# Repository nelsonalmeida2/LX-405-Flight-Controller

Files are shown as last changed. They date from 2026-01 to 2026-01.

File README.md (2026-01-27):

<div align="center">

# 🚁 LX-405 Flight Controller

<div align="center">
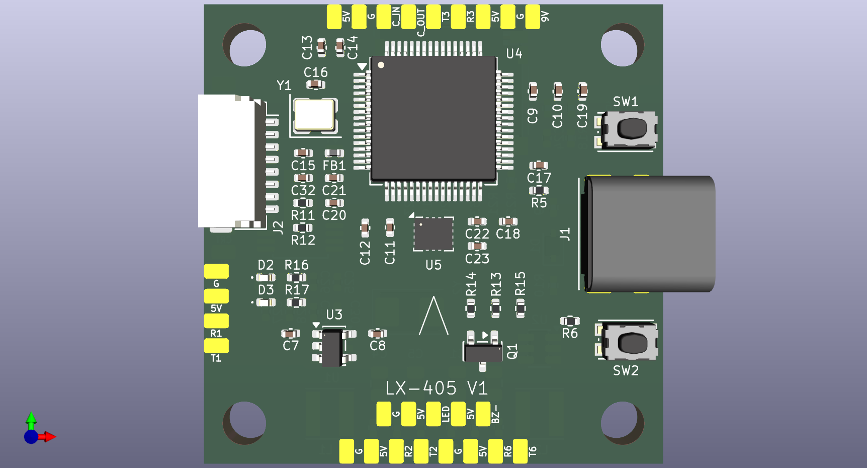
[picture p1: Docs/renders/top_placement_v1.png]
LX-405 PCB Placement
  
</div>

**A robust, Open Source FPV Flight Controller designed by a Computer Engineering student.**






</div>

---

## 🎯 Motivation & Philosophy

> *"In the modern era, Artificial Intelligence combined with human effort makes the impossible, inevitable."*

The **LX-405** project was born from a realization: as a Computer Engineering student entering the high-speed world of FPV, I found that too many flight controllers on the market suffer from electrical noise, weak regulators, and fragility under 6S voltage spikes.

My goal is to prove that **modern engineering is boundary-less**. Even though my degree is not strictly focused on electronics, the foundational skills acquired in my academic path—combined with a self-taught mindset and the leverage of **Large Language Models (LLMs)** as advanced design assistants—allow for the creation of professional-grade hardware.

This project demonstrates that with the right theoretical foundations and modern AI tools, it is possible to design a Flight Controller that is **more robust, cleaner, and potentially more cost-effective** at scale.

### 📐 Design Strategy: Modular & Hierarchical
Unlike typical hobbyist "flat" schematics, the LX-405 follows a strict **Hierarchical Design** approach.
Applying the software engineering principle of **Modularity** (Separation of Concerns), the hardware is divided into distinct hierarchical subsystems:
* **Power Management:** Encapsulates the voltage regulation logic (5V, 9V, 3.3V) with clean "Power Flags" logic.
* **MCU Core:** Contains the processor logic, clock, signaling, and boot configuration.
* **System Peripherals:** Groups active sensors (Gyro, Baro), OSD video processing logic, **Blackbox Logging**, and user feedback systems (LEDs/Buzzer).
* **Connectors IO:** Isolates physical interface definitions (plugs/pads) from logical connections to prevent routing conflicts.

### 🎓 Academic Foundations
This design applies core concepts from my Computer Engineering curriculum at **Universidade Lusófona**:
* **Digital Systems:** Logic gates and boolean algebra applied to circuit switching.
* **Computer Architecture:** Understanding CPU data paths, buses, registers, and instruction execution.
* **Advanced Computer Architectures:** Knowledge of processor constraints, memory hierarchy (cache), and hardware-software interaction.
* **Fundamentals of Physics:** Electromagnetism, electric fields, circuit analysis, and DC power dynamics.

---

## ⚡ Technical Specifications

### 🧠 Core System (Schematic Completed)
* **MCU:** STM32F405RGT6 (168MHz, 1MB Flash).
* **Clock:** 8MHz HSE Crystal Oscillator with 22pF load caps for precision timing.
* **Signal Integrity:** Dedicated LC Filter (Ferrite Bead + Caps) for **VDDA** analog noise suppression.
* **Safety:** Hardware-implemented Watchdog (NRST) and Bootloader (BOOT0) physical controls.

### 📡 Connectivity & Protocols
* **USB Interface:** Modern **USB-C** connector with dedicated ESD protection lines for firmware updates and Betaflight configuration.
* **Motor Protocols:**
    * 4x DSHOT Outputs (Timer-mapped for DMA collision avoidance).
    * **Redundant ESC Pads:** Parallel solder pads for motor signals, allowing field repairs if the main JST connector breaks.
* **Communication Ports:** 5x UARTs fully mapped for versatility:
    * **UART 1:** RC Link (ELRS / Crossfire).
    * **UART 2:** GPS / General Purpose.
    * **UART 3:** **Video Link** (SmartAudio for Analog **OR** MSP for DJI O3/HDZero).
    * **UART 4:** ESC Telemetry (Sensor Input).
    * **UART 6:** Peripheral Expansion (Bluetooth, Lidar, Secondary GPS).
    * *(Note: UART 5 was replaced by the High-Speed SDIO Bus).*
* **Video System (Hybrid):**
    * Dedicated **"Hybrid Power Pad"** offering both **5V** (Analog) and **9V** (High Power Digital) options for the VTX.
    * **Analog OSD:** **MAX7456** (or **AT7456E**) on SPI2 with dedicated video filtering.
* **Sensor Bus:** Dedicated SPI1 (High-Speed Gyro) and I2C1 (Barometer).

### 🛡️ On-Board Sensors & Peripherals
* **IMU (Gyroscope):** **BMI270** connected via Low-Noise **SPI1**.
    * Features hardware **EXTI Interrupt** (PC4) for ultra-low latency loop synchronization.
* **Barometer:** **DPS310** connected via **I2C1** for high-precision altitude hold.
* **Blackbox Logging:** **MicroSD Card Slot** via **4-bit SDIO** Interface.
    * Superior performance compared to SPI logging, enabling high-frequency data recording without CPU bottlenecks.
* **User Feedback:**
    * **Status LEDs:** Dedicated **LED_POWER** (Red) and **LED_STATUS** (Blue) for instant system diagnostics.
    * **Buzzer Driver:** Integrated active buzzer circuit for alarms and "turtle mode" feedback.

### 🔋 Power Plant (Tri-Rail Architecture)
A hierarchical power distribution system designed to minimize noise coupling and maximize versatility:

| Rail | Regulator | Specs | Application |
| :--- | :--- | :--- | :--- |
| **Input** | XT60 Direct | **3S-6S (10V - 25.2V)** | Wide-range input for Cinematic (6S) & Freestyle (4S) |
| **9V Rail** | TPS54302 | 3A Buck | **Hybrid Video Ready:** Supports DJI O3/Vista & Analog VTX |
| **5V Rail** | TPS54302 | 3A Buck | GPS, ELRS Receiver, Buzzer, OSD Chip |
| **3.3V Rail** | AP2112K | 500mA LDO | **Ultra-Low Noise** for MCU, Gyro, Baro & Blackbox |

---

## 📂 Repository Structure

```text
LX-405-Flight-Controller/
├── 📂 Hardware/          # KiCad Project Files (Schematics, PCB & Symbols)
├── 📂 Schematic/         # PDF Exports for easy viewing
├── 📂 Docs/              # Datasheets and Engineering Notes
├── 📄 LICENSE            # MIT License details
└── 📄 README.md          # Documentation
```
## 🛠 Development Roadmap

### Phase 1: Schematic Design 🔌

- [x] **Power Management**
    - [x] Input Stage: TVS protection and bulk capacitance (3S–6S filtering)
    - [x] 5V Regulator: Synchronous buck (TPS54302)
    - [x] 9V Regulator: High-current buck (TPS54302) for HD video
    - [x] 3.3V Regulator: Low-noise LDO (AP2112K) for sensors

- [x] **MCU Core**
    - [x] STM32F405RGT6: Symbol integration and pin definition
    - [x] Power decoupling & analog filtering (VDDA)
    - [x] Clock system: 8 MHz HSE crystal
    - [x] I/O architecture: Full UART / SPI / I2C mapping validation

- [x] **System Peripherals**
    - [x] Gyroscope (BMI270) via SPI1
    - [x] Barometer (DPS310) via I2C with address fix
    - [x] Blackbox: High-speed SDIO MicroSD slot implementation
    - [x] On-screen display (MAX7456 / AT7456E) via SPI2
    - [x] Visual / Audio: Status LEDs & buzzer circuit implemented

- [x] **Connectors & I/O**
    - [x] USB-C interface (data lines & ESD protection logic)
    - [x] ESC connector (standard pinout with telemetry)
    - [x] ESC redundancy: Parallel solder pads for emergency field repairs
    - [x] Hybrid VTX connector (selectable 5V / 9V)

- [x] **Design Validation**
    - [x] Electrical Rules Check (ERC): **PASSED with 0 errors**
    - [x] Schematic design finalized (**v0.6**)

### Phase 2: PCB Layout 📐

- [x] **Physical Implementation**
    - [x] Assign footprints (associating symbols with physical dimensions)
    - [x] Stackup definition (4-layer)
    - [x] Component placement (Optimized for noise reduction & assembly)
    - [x] Silkscreen & Labeling (User-friendly pin identification)
    - [ ] Routing (Traces & Ground Planes)
    - [ ] DRC (Design Rules Check) & Fabrication Output (Gerbers)

---

## 📜 License

This project is licensed under the **MIT License** — see the `LICENSE` file for details.

You are free to use, modify, and distribute this hardware design for private or commercial use, provided you include the original copyright notice.

As an **Open Source Hardware** project, contributions and forks are welcome.

---

<div align="center">

**Designed in Lisbon, Portugal 🇵🇹**  
Powered by Engineering Fundamentals & AI

</div>

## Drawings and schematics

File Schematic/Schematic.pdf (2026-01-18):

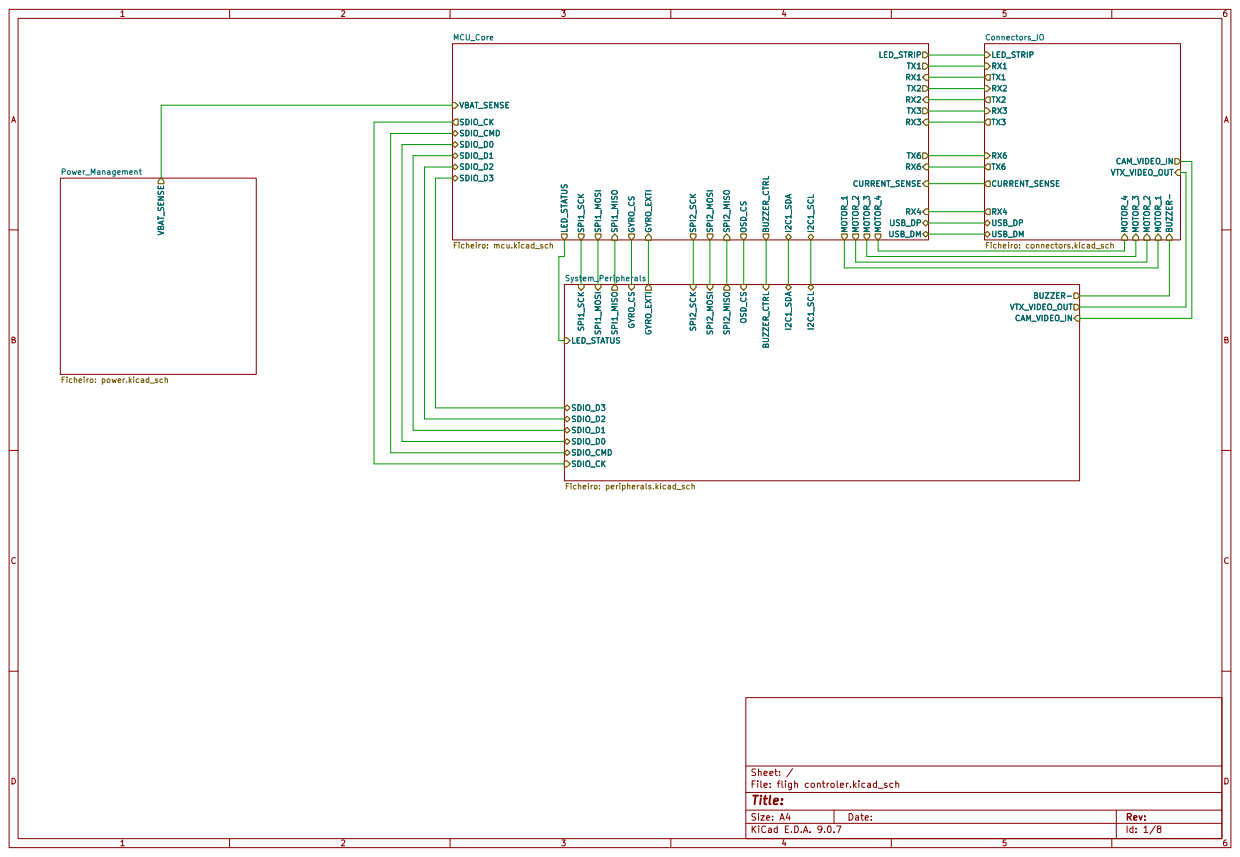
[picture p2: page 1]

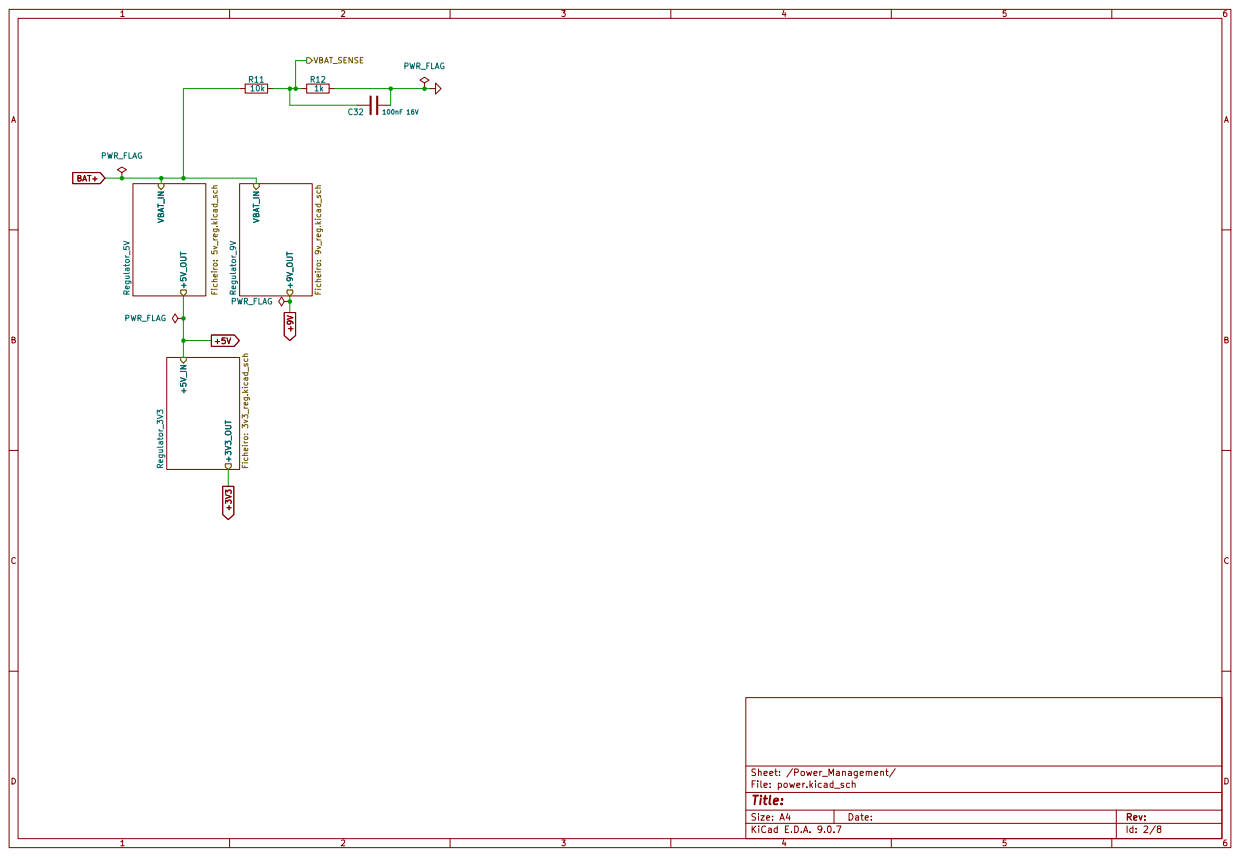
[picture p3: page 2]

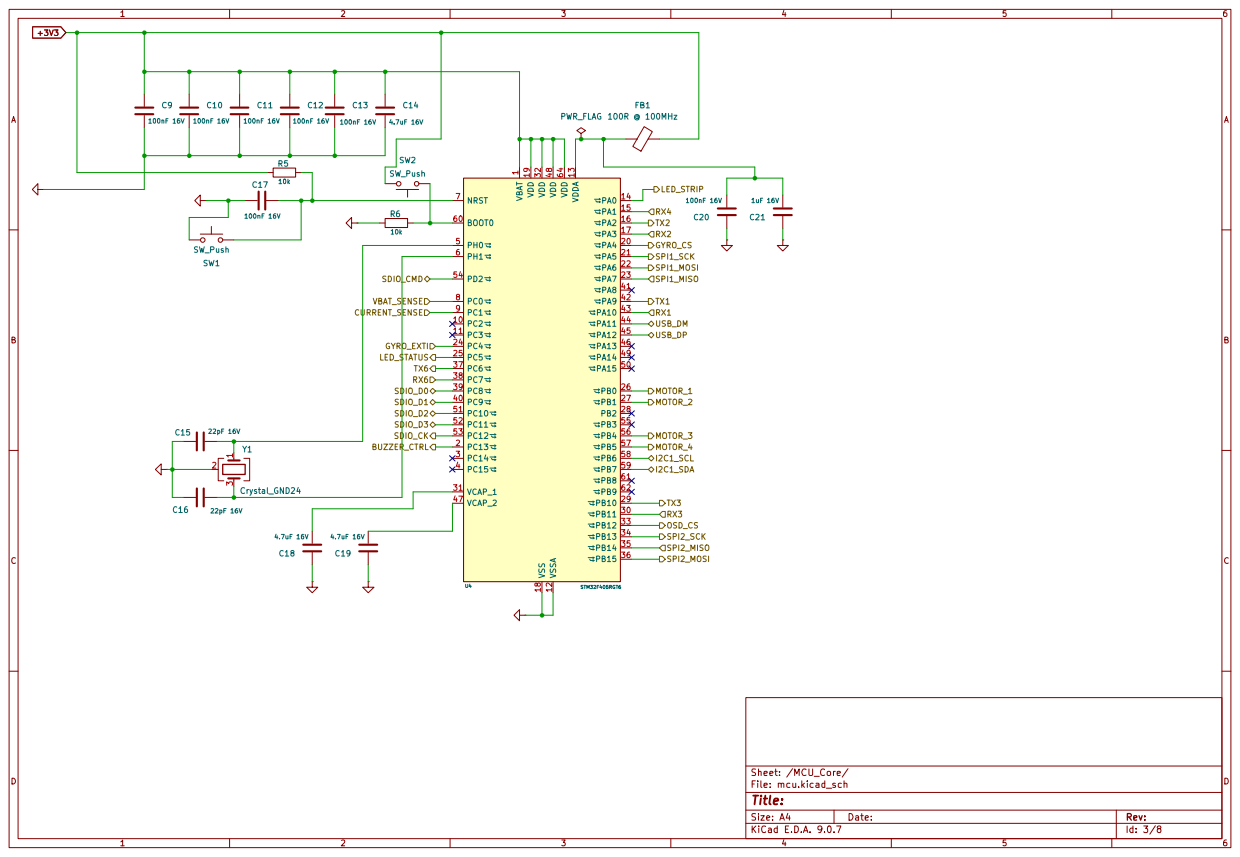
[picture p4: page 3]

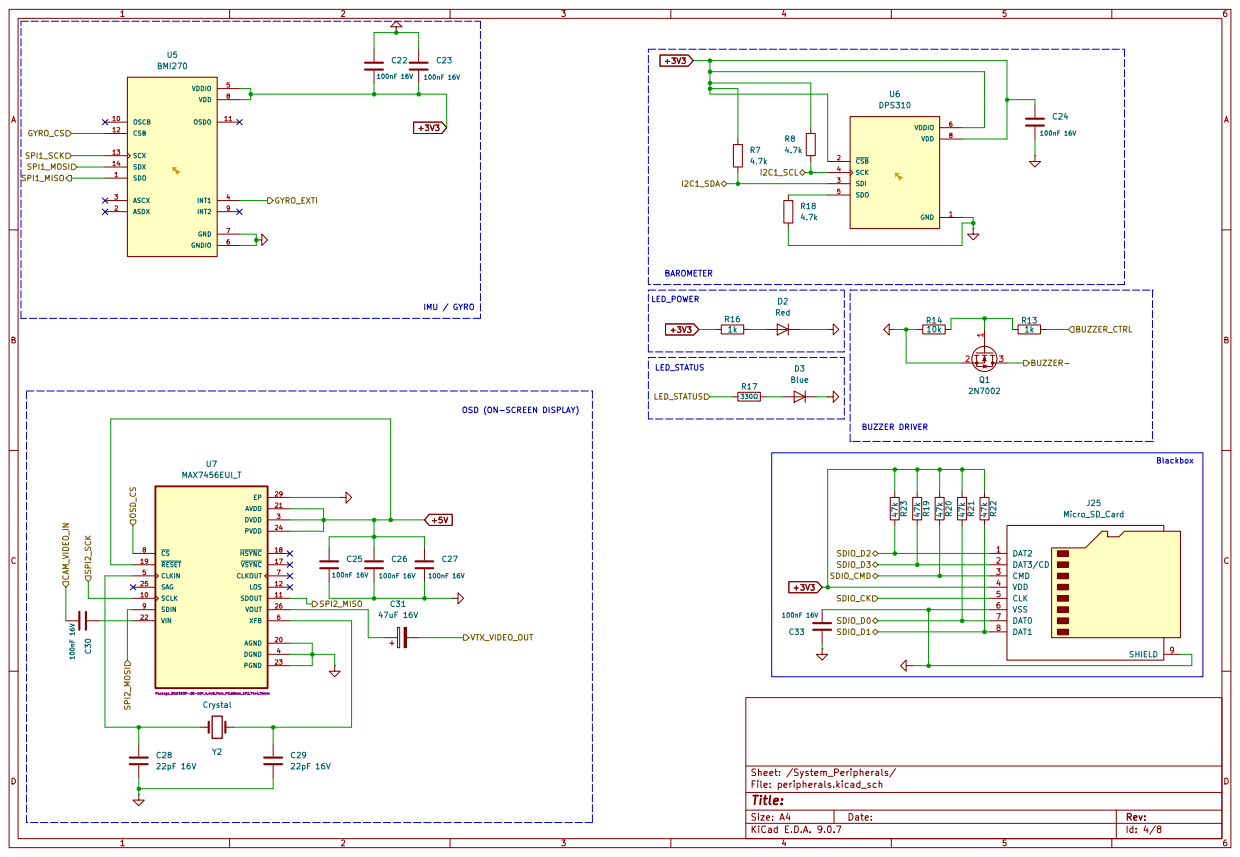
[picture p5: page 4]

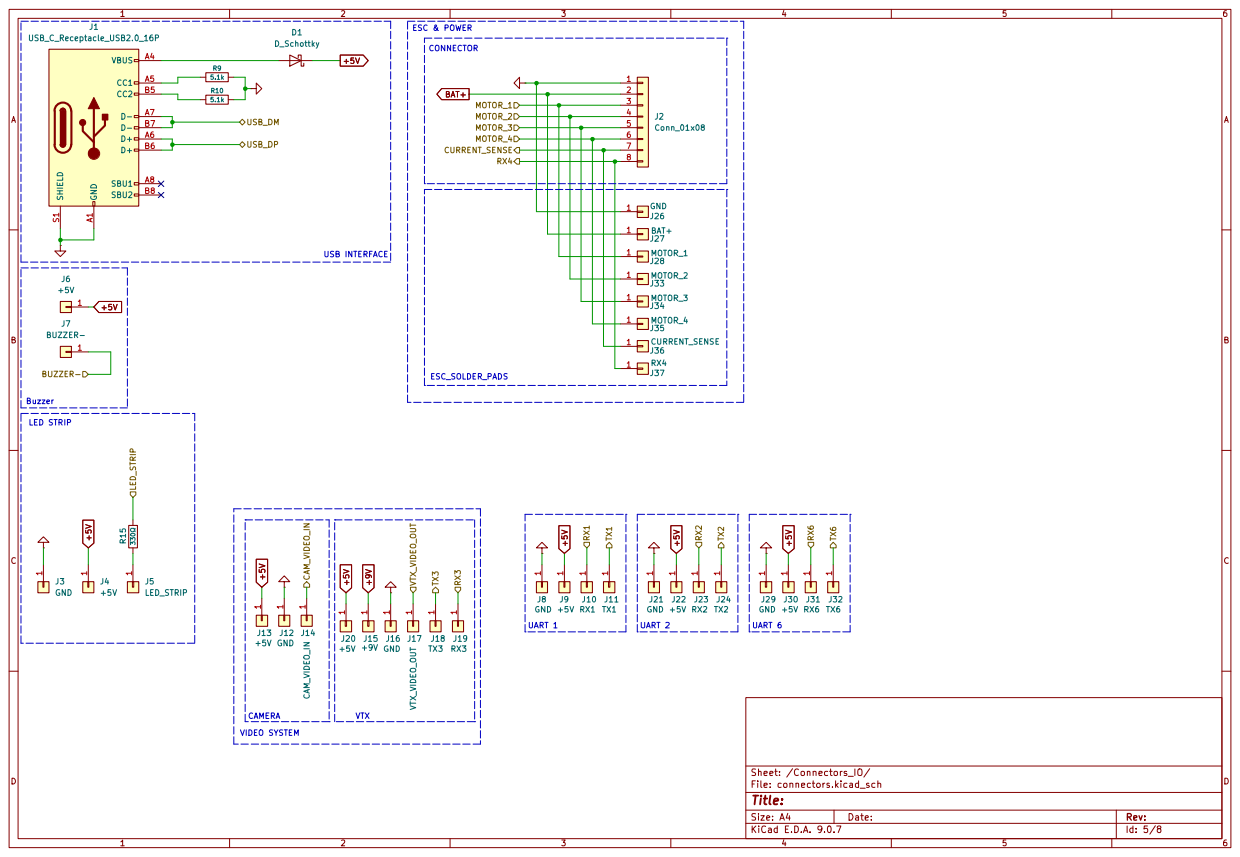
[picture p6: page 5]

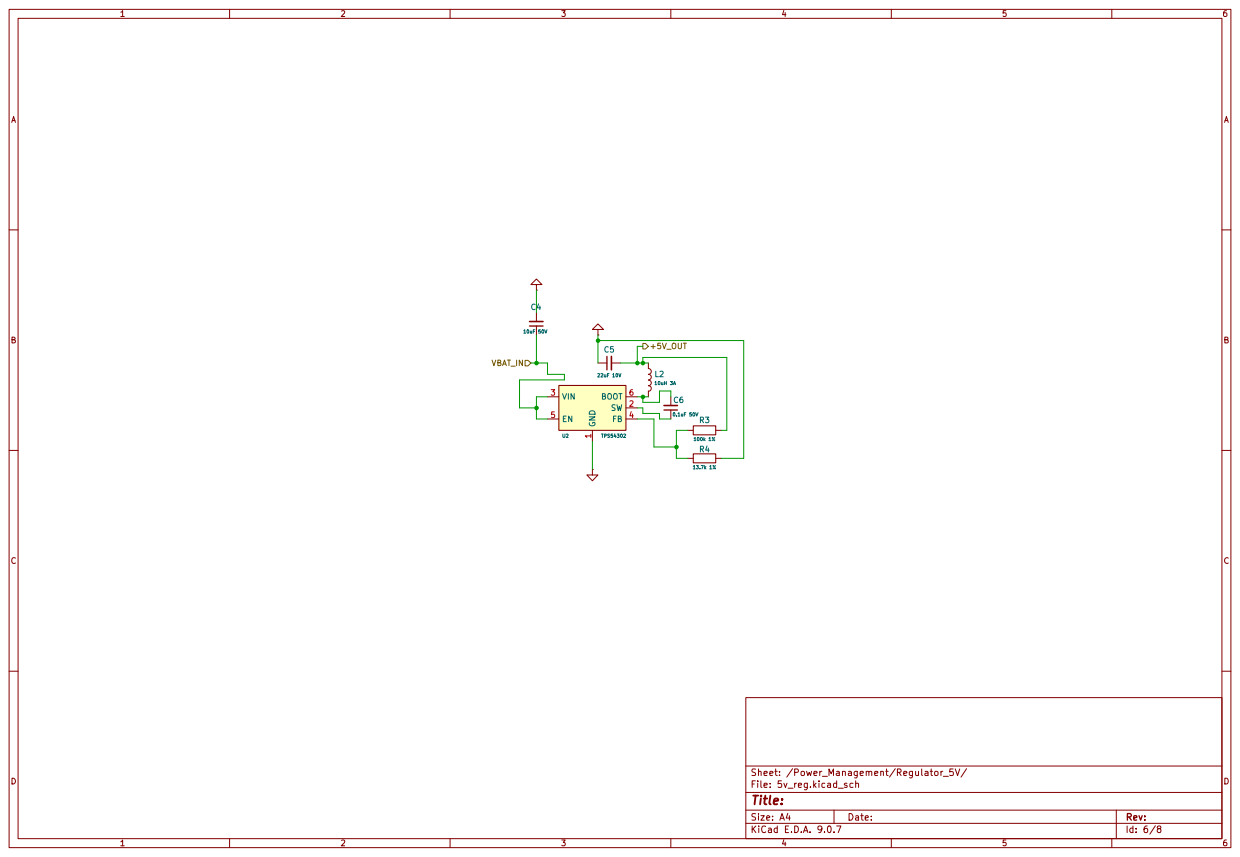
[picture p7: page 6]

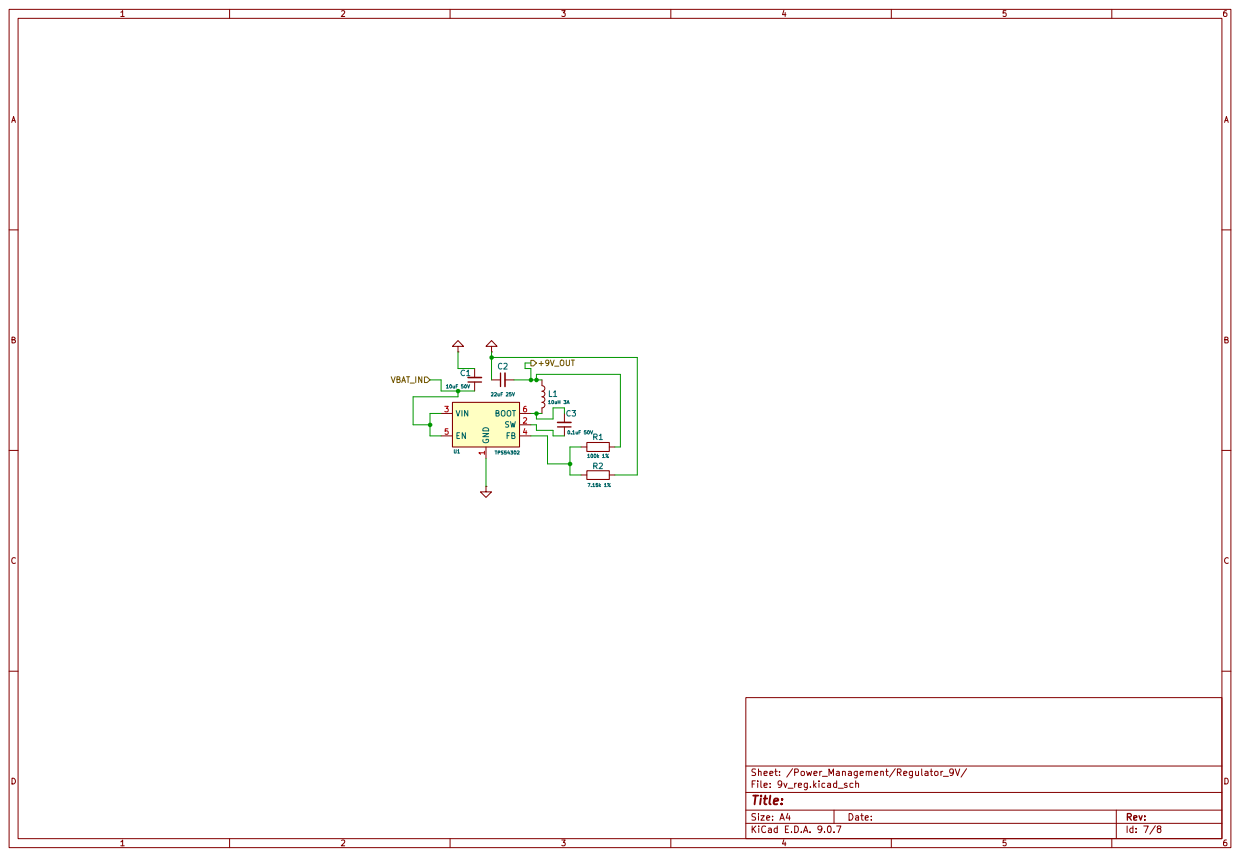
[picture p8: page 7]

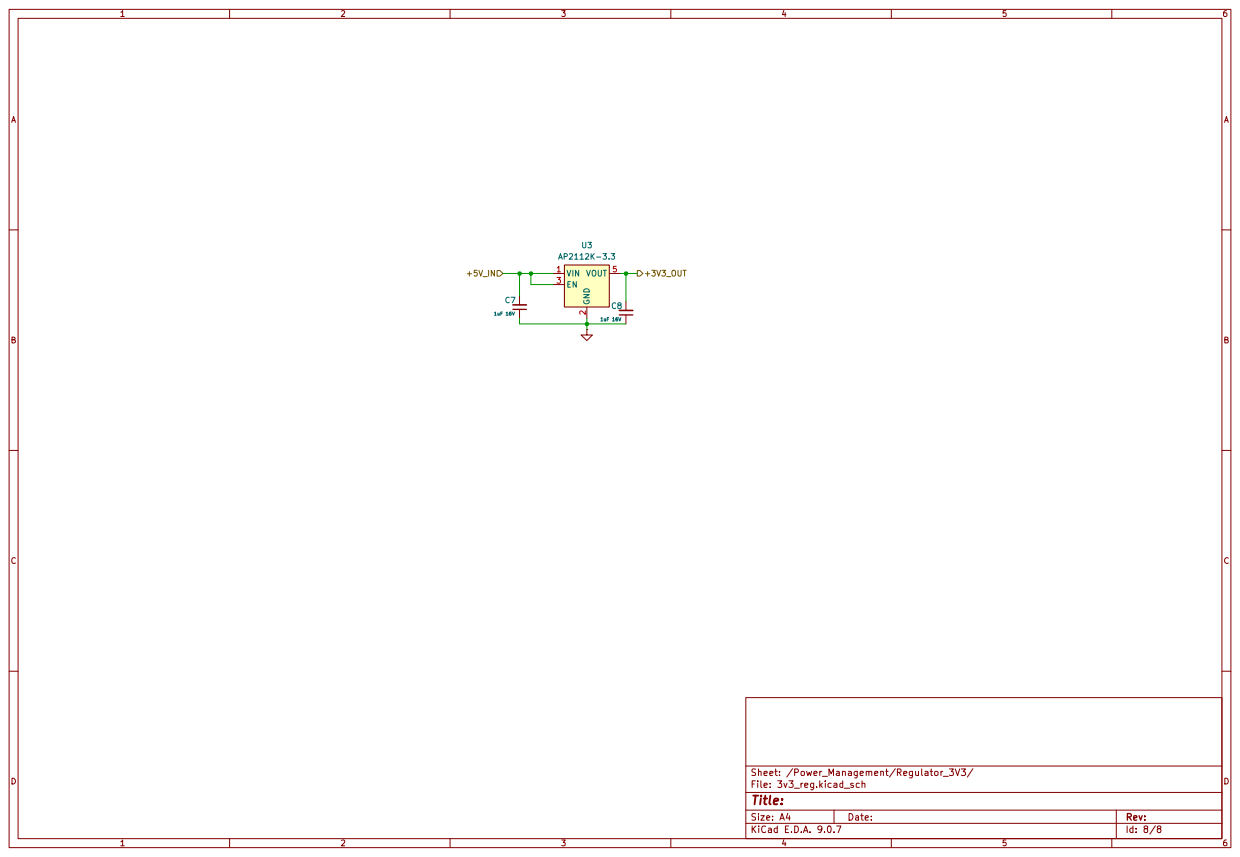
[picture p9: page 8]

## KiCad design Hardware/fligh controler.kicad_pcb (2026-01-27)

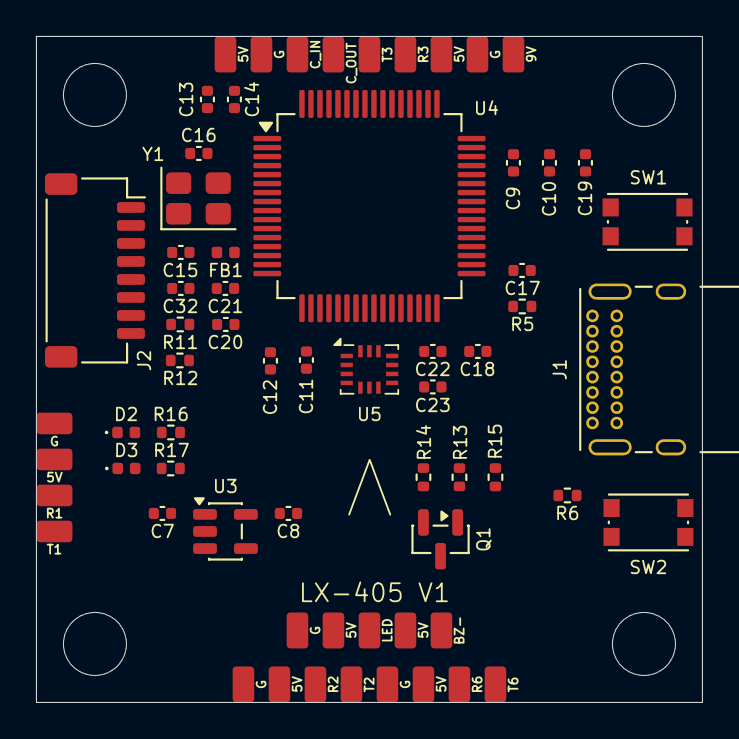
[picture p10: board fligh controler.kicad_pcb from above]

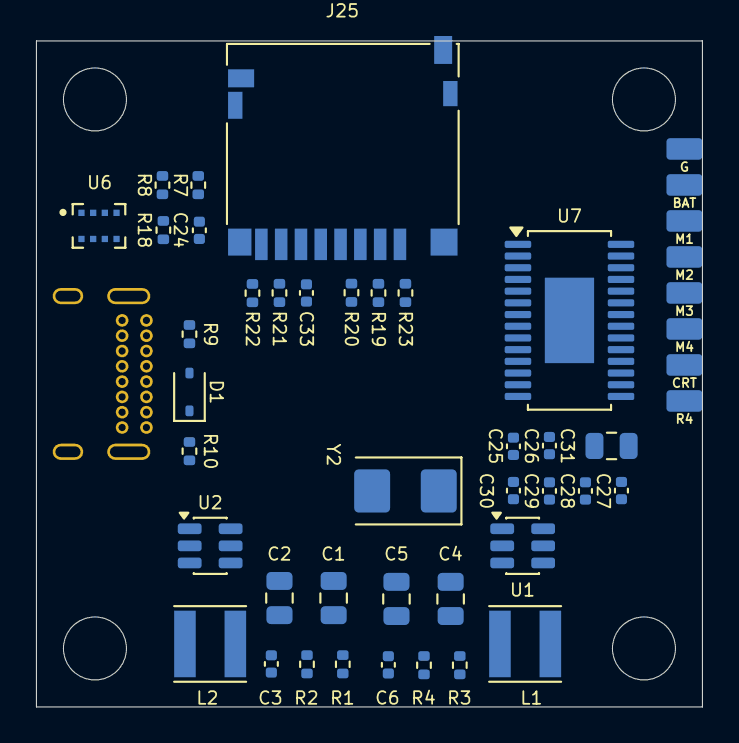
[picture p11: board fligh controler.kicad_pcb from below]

Board: 2 copper layers, 37.0 x 37.0 mm, 111 parts (46 on the bottom side), 70 nets, no tracks yet.

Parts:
5V, 5V#2, 5V#3, 5V#4, 5V#5, 5V#6, 5V#7: +5V; Pad_TestPoint_Retangular
9V: +9V; Pad_TestPoint_Retangular
BAT: BAT+; Pad_TestPoint_Retangular
BZ-: BUZZER-; Pad_TestPoint_Retangular
C1, C4: 10uF 50V; C_0805_2012Metric
C2: 22uF 25V; C_0805_2012Metric
C3, C6: 0.1uF 50V; C_0402_1005Metric
C5: 22uF 10V; C_0805_2012Metric
C7, C8, C21: 1uF 16V; C_0402_1005Metric
C9, C10, C11, C12, C13, C17, C20, C22, C23, C24, C25, C26, C27, C30, C32, C33: 100nF 16V; C_0402_1005Metric
C14, C18, C19: 4.7uF 16V; C_0402_1005Metric
C15, C16, C28, C29: 22pF 16V; C_0402_1005Metric
C31: 47uF 16V; C_0805_2012Metric
CRT: CURRENT_SENSE; Pad_TestPoint_Retangular
C_IN: CAM_VIDEO_IN; Pad_TestPoint_Retangular
C_OUT: VTX_VIDEO_OUT; Pad_TestPoint_Retangular
D1: D_Schottky; D_SOD-323
D2: Red; LED_0402_1005Metric
D3: Blue; LED_0402_1005Metric
FB1: 100R @ 100MHz; L_0402_1005Metric
G: GND; Pad_TestPoint_Retangular
G#2, G#3, G#4, G#5, G#6, G#7: GND; Pad_TestPoint_Retangular
J1: USB_C_Receptacle_USB2.0_16P; USB_C_Receptacle_GCT_USB4085
J2: Conn_01x08; JST_SH_SM08B-SRSS-TB_1x08-1MP_P1.00mm_Horizontal
J25: Micro_SD_Card; microSD_HC_Hirose_DM3D-SF
L1, L2: 10uH 3A; L_Taiyo-Yuden_NR-40xx
LED: LED_STRIP; Pad_TestPoint_Retangular
M1: MOTOR_1; Pad_TestPoint_Retangular
M2: MOTOR_2; Pad_TestPoint_Retangular
M3: MOTOR_3; Pad_TestPoint_Retangular
M4: MOTOR_4; Pad_TestPoint_Retangular
Q1: 2N7002; SOT-23
R1: RX1; Pad_TestPoint_Retangular
R1#2, R3#2: 100k 1%; R_0402_1005Metric
R2: RX2; Pad_TestPoint_Retangular
R2#2: 7.15k 1%; R_0402_1005Metric
R3: RX3; Pad_TestPoint_Retangular
R4: RX4; Pad_TestPoint_Retangular
R4#2: 13.7k 1%; R_0402_1005Metric
R5, R6, R11, R14: 10k; R_0402_1005Metric
R6#2: RX6; Pad_TestPoint_Retangular
R7, R8, R18: 4.7k; R_0402_1005Metric
R9, R10: 5.1k; R_0402_1005Metric
R12, R13, R16: 1k; R_0402_1005Metric
R15, R17: 330Ω; R_0402_1005Metric
R19, R20, R21, R22, R23: 47k; R_0402_1005Metric
SW1, SW2: SW_Push; SW_Push_1P1T_NO_CK_KMR2
T1: TX1; Pad_TestPoint_Retangular
T2: TX2; Pad_TestPoint_Retangular
T3: TX3; Pad_TestPoint_Retangular
T6: TX6; Pad_TestPoint_Retangular
U1, U2: TPS54302; SOT-23-6
U3: AP2112K-3.3; SOT-23-5
U4: STM32F405RGT6; LQFP-64_10x10mm_P0.5mm
U5: BMI270; Bosch_LGA-14_3x2.5mm_P0.5mm
U6: DPS310
U7: MAX7456EUI_T; TSSOP-28-1EP_4.4x9.7mm_P0.65mm_EP2.74x4.75mm
Y1: Crystal_GND24; Crystal_SMD_3225-4Pin_3.2x2.5mm
Y2: Crystal; Crystal_SMD_5032-2Pin_5.0x3.2mm

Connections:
+3V3: C8.2, C9.1, C10.1, C11.1, C12.1, C13.1, C14.1, C22.2, C23.2, C24.1, FB1.2, J25.4 (VDD), R5.1, R7.1, R8.2, R16.1, R19.1, R20.1, R21.1, R22.1, R23.1, SW2.2, U3.5 (VOUT), U4.1 (VBAT), U4.19 (VDD), U4.32 (VDD), U4.48 (VDD), U4.64 (VDD), U5.5 (VDDIO), U5.8 (VDD), U6.2 (~CSB), U6.6 (VDDIO), U6.8 (VDD)
+5V: 5V.1, 5V#2.1, 5V#3.1, 5V#4.1, 5V#5.1, 5V#6.1, 5V#7.1, C5.2, C7.2, C25.1, C26.1, C27.1, D1.1 (K), L2.1, R3#2.2, U3.1 (VIN), U3.3 (EN), U7.3 (DVDD), U7.19 (~RESET), U7.21 (AVDD), U7.24 (PVDD)
+9V: 9V.1, C2.2, L1.1, R1#2.2
/Connectors_IO/BUZZER-: BZ-.1, Q1.3 (D)
/Connectors_IO/CAM_VIDEO_IN: C30.2, C_IN.1
/Connectors_IO/CURRENT_SENSE: CRT.1, J2.7, U4.9 (PC1)
/Connectors_IO/LED_STRIP: R15.1, U4.14 (PA0)
/Connectors_IO/MOTOR_1: J2.3, M1.1, U4.26 (PB0)
/Connectors_IO/MOTOR_2: J2.4, M2.1, U4.27 (PB1)
/Connectors_IO/MOTOR_3: J2.5, M3.1, U4.56 (PB4)
/Connectors_IO/MOTOR_4: J2.6, M4.1, U4.57 (PB5)
/Connectors_IO/RX1: R1.1, U4.42 (PA9)
/Connectors_IO/RX2: R2.1, U4.16 (PA2)
/Connectors_IO/RX3: R3.1, U4.29 (PB10)
/Connectors_IO/RX4: J2.8, R4.1, U4.15 (PA1)
/Connectors_IO/RX6: R6#2.1, U4.37 (PC6)
/Connectors_IO/TX1: T1.1, U4.43 (PA10)
/Connectors_IO/TX2: T2.1, U4.17 (PA3)
/Connectors_IO/TX3: T3.1, U4.30 (PB11)
/Connectors_IO/TX6: T6.1, U4.38 (PC7)
/Connectors_IO/USB_DM: J1.A7 (D-), J1.B7 (D-), U4.44 (PA11)
/Connectors_IO/USB_DP: J1.A6 (D+), J1.B6 (D+), U4.45 (PA12)
/Connectors_IO/VTX_VIDEO_OUT: C31.2, C_OUT.1
/MCU_Core/BUZZER_CTRL: R13.2, U4.2 (PC13)
/MCU_Core/GYRO_CS: U4.20 (PA4), U5.12 (CSB)
/MCU_Core/GYRO_EXTI: U4.24 (PC4), U5.4 (INT1)
/MCU_Core/I2C1_SCL: R8.1, U4.58 (PB6), U6.4 (SCK)
/MCU_Core/I2C1_SDA: R7.2, U4.59 (PB7), U6.3 (SDI)
/MCU_Core/LED_STATUS: R17.1, U4.25 (PC5)
/MCU_Core/OSD_CS: U4.33 (PB12), U7.8 (~CS)
/MCU_Core/SDIO_CK: J25.5 (CLK), U4.53 (PC12)
/MCU_Core/SDIO_CMD: J25.3 (CMD), R20.2, U4.54 (PD2)
/MCU_Core/SDIO_D0: J25.7 (DAT0), R21.2, U4.39 (PC8)
/MCU_Core/SDIO_D1: J25.8 (DAT1), R22.2, U4.40 (PC9)
/MCU_Core/SDIO_D2: J25.1 (DAT2), R23.2, U4.51 (PC10)
/MCU_Core/SDIO_D3: J25.2 (DAT3/CD), R19.2, U4.52 (PC11)
/MCU_Core/SPI1_MISO: U4.23 (PA7), U5.1 (SDO)
/MCU_Core/SPI1_MOSI: U4.22 (PA6), U5.14 (SDX)
/MCU_Core/SPI1_SCK: U4.21 (PA5), U5.13 (SCX)
/MCU_Core/SPI2_MISO: U4.35 (PB14), U7.11 (SDOUT)
/MCU_Core/SPI2_MOSI: U4.36 (PB15), U7.9 (SDIN)
/MCU_Core/SPI2_SCK: U4.34 (PB13), U7.10 (SCLK)
/MCU_Core/VBAT_SENSE: C32.2, R11.1, R12.2, U4.8 (PC0)
BAT+: BAT.1, C1.1, C4.1, J2.2, R11.2, U1.3 (VIN), U1.5 (EN), U2.3 (VIN), U2.5 (EN)
GND: C1.2, C2.1, C4.2, C5.1, C7.1, C8.1, C9.2, C10.2, C11.2, C12.2, C13.2, C14.2, C15.1, C16.1, C17.1, C18.1, C19.1, C20.1, C21.1, C22.1, C23.1, C24.2, C25.2, C26.2, C27.2, C28.2, C29.2, C32.1, C33.1, C33.2, D2.1 (K), D3.1 (K), G.1, G#2.1, G#3.1, G#4.1, G#5.1, G#6.1, G#7.1, J1.A1 (GND), J1.A12 (GND), J1.B1 (GND), J1.B12 (GND), J1.S1 (SHIELD), J2.1, J25.6 (VSS), J25.9 (SHIELD), Q1.2 (S), R2#2.1, R4#2.1, R6.1, R9.2, R10.2, R12.1, R14.1, R18.2, SW1.1, U1.1 (GND), U2.1 (GND), U3.2 (GND), U4.12 (VSSA), U4.18 (VSS), U4.63 (VSS), U5.6 (GNDIO), U5.7 (GND), U6.1 (GND), U6.7 (GND), U7.4 (DGND), U7.20 (AGND), U7.23 (PGND), U7.29 (EP), Y1.2 (G), Y1.4 (G)
unnamed: D1.2 (A), J1.A4 (VBUS), J1.A9 (VBUS), J1.B4 (VBUS), J1.B9 (VBUS)
unnamed: D2.2 (A), R16.2
unnamed: D3.2 (A), R17.2
unnamed: J1.A5 (CC1), R9.1
unnamed: J1.B5 (CC2), R10.1
unnamed: LED.1, R15.2
unnamed: Q1.1 (G), R13.1, R14.2
unnamed: C3.2, L1.2, U1.6 (BOOT)
unnamed: R1#2.1, R2#2.2, U1.4 (FB)
unnamed: C3.1, U1.2 (SW)
unnamed: C6.2, L2.2, U2.6 (BOOT)
unnamed: R3#2.1, R4#2.2, U2.4 (FB)
unnamed: C6.1, U2.2 (SW)
unnamed: R6.2, SW2.1, U4.60 (BOOT0)
unnamed: C17.2, R5.2, SW1.2, U4.7 (NRST)
unnamed: C15.2, U4.5 (PH0), Y1.1
unnamed: C16.2, U4.6 (PH1), Y1.3
unnamed: C18.2, U4.31 (VCAP_1)
unnamed: C19.2, U4.47 (VCAP_2)
unnamed: C20.2, C21.2, FB1.1, U4.13 (VDDA)
unnamed: R18.1, U6.5 (SDO)
unnamed: C28.1, U7.5 (CLKIN), Y2.2
unnamed: C30.1, U7.22 (VIN)
unnamed: C31.1, U7.26 (VOUT)
unnamed: C29.1, U7.6 (XFB), Y2.1

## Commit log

2026-01-16 Initial Commit: Project structure, README, and Power Management module
    [3v3_reg.kicad_sch, 5v_reg.kicad_sch, 9v_reg.kicad_sch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]
2026-01-17 feat(mcu): finalize core schematic and update project documentation
    - MCU_Core: Completed pin definitions and Hierarchical Labels (SPI, UART, I2C, Motors).
    - Root: Updated sheet pins to reflect the new MCU architecture.
    - Docs: Refined README.md with detailed hierarchical roadmap and MIT License.
    - Docs: Added 'Connectors & I/O' breakdown to the development plan.
    [fligh controler.kicad_sch, mcu.kicad_sch]
2026-01-17 feat: implement system peripherals (OSD, Gyro, Baro)
    [fligh controler.kicad_sch, mcu.kicad_sch, peripherals.kicad_sch]
2026-01-18 Finalize schematic: Add connectors, LEDs, Buzzer and fix all ERC errors
    [3v3_reg.kicad_sch, 5v_reg.kicad_sch, 9v_reg.kicad_sch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]
2026-01-18 Update schematic: Add SDIO Blackbox, ESC Redundancy and remove UART5
    [5v_reg.kicad_sch, 9v_reg.kicad_sch, connectors.kicad_sch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]
2026-01-27 Finalize component placement and silkscreen
    [3v3_reg.kicad_sch, 5v_reg.kicad_sch, 9v_reg.kicad_sch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]
